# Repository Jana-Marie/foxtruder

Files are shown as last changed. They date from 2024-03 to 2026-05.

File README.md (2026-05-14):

# permanently moved to [codeberg/janam/foxtruder](https://codeberg.org/janam/foxtruder)

# foxtruder

**~~froggy~~**, **~~fog-o-nozzle~~**, **~~multimist~~**, **foxtruder [working title]** is a tiny fog machine powered by USB-PD, with Wifi and Bluetooth, based around a 3D-printer heat-cartridge and nozzle. As much as I wish to call this the worlds smallest **intentional** fog machine, sadly disposable vapes exist. Otherwise this one would be atop of the smaller fog-machines. To make it this small however, it requires an external pump, or rather a pressurized fog-fluid line, which can be connected to the 4mm pneumatic connector at the bottom. The idea here is to just have one fog-juice reservoir and pump for many fog machines. A valve on the board is used to switch the fog.

 - **Size:** 70x70x35mm
 - **Power-In:** 12-24V DC, USB-PD
 - **Communication:** RS485, DMX, WIFI, BLE, USB (Python Shell)
 - **Indication:** 4 Status LEDs, 5 Effect LEDs
 - **IO:** RS485, External IO, 2 Buttons, 4mm pneumatic push connector (fluid in), Fan Connector, I2C

Now, you might ask **why**?? To be clear, this is a stupid idea, an intrusive thought turned reality if you will, I'm not even sure if I can recommend you to replicate this. However, the tiny size combined with the low cost per machine of ~20-40€ makes this perfect for larger art-installations requiring fog. Or even better use the fog as the medium of visual art. I.e. in an array, linear arrangement, circular fashion or just many small distributed points of fog generation.

<table>
  <tbody>
    <tr>
      <td>
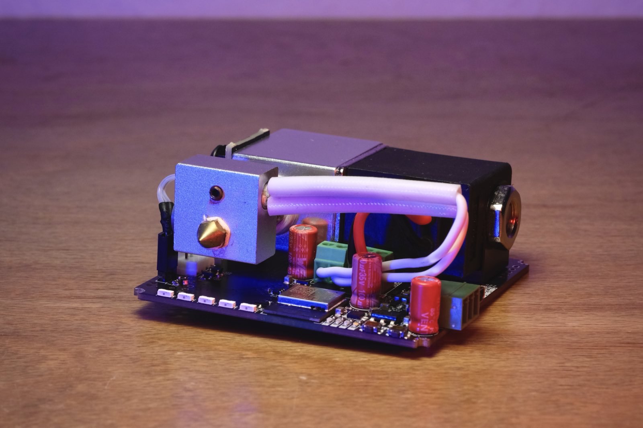
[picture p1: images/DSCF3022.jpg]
        
      </td>
      <td>
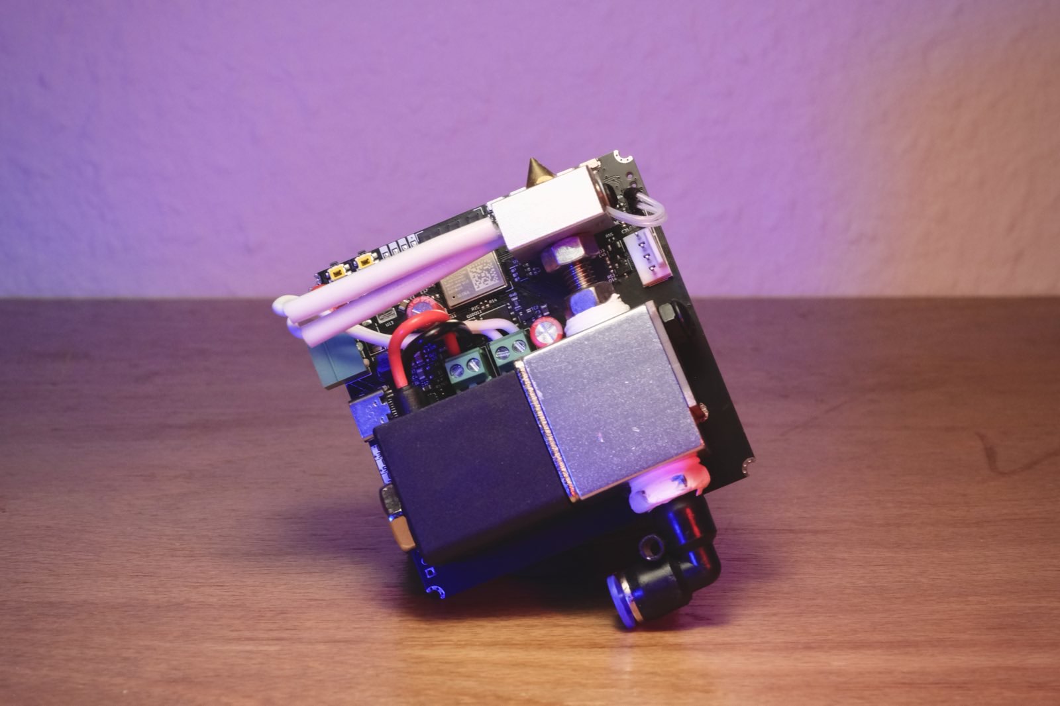
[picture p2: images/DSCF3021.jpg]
        
      </td>
    </tr>
  </tbody>
</table>

I guess this exists now, enjoy?.

<table>
  <tbody>
    <tr>
      <td width="68%">
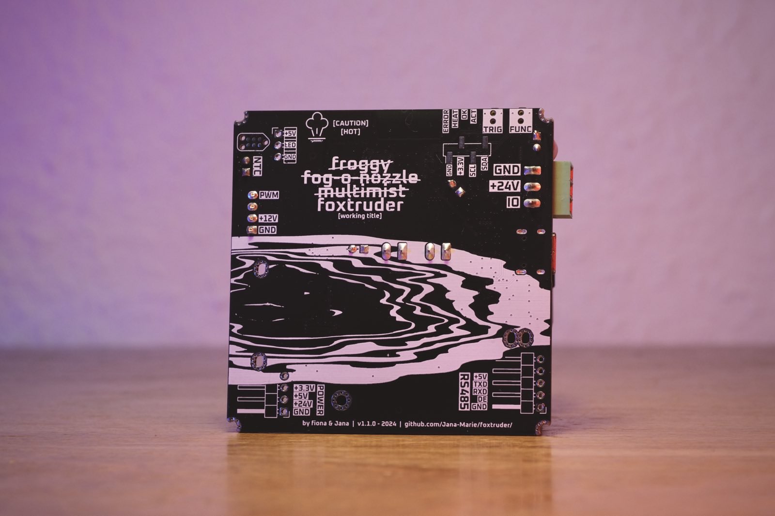
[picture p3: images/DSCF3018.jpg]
        
      </td>
      <td>
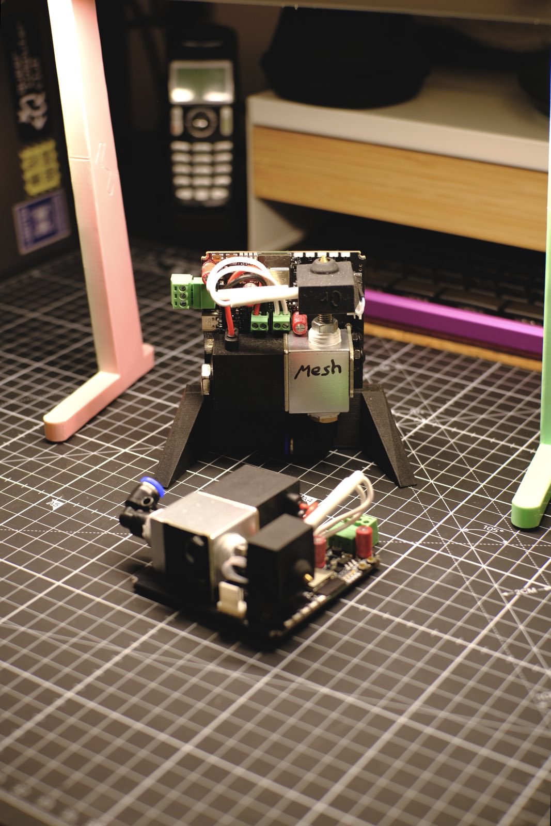
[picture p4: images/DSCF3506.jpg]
        
      </td>
    </tr>
  </tbody>
</table>

### State of this project and learnings

**It is not recommended to replicate this project in its current form, it is more of an experiment than a proper fog machine.** Issues to be solved include but are not limited to:

 - Spitting, the fog machine tends to not convert all fog-juice into fog
 - BOM cost, it should be optimized
 - Mechanical complexity, the valve-hotend interface requires some odd machining
 - Assembly complexity is too high
 - Open health questions, it seems that fog-juice may be unhealthy when heated above 190°C, however for a proper, spit-free operation temperatures well above 250-300°C might be desired (as with commercial fog machines)

### FAQ

##### Can this be run off a MacBooks USB-PD port?

Yes, that was the main mean of development.

### Initial block diagram

This needs updating, but this was the initial idea. The fog-juice tank is an external component now and the additional airflow controller to disturb the fog has not been implemented yet. Otherwise this is fairly true to foxtruder. The fog-juice tank is a real thing and has an input for pressurized air and an outlet for the liquid.

<table>
  <tbody>
    <tr>
      <td>
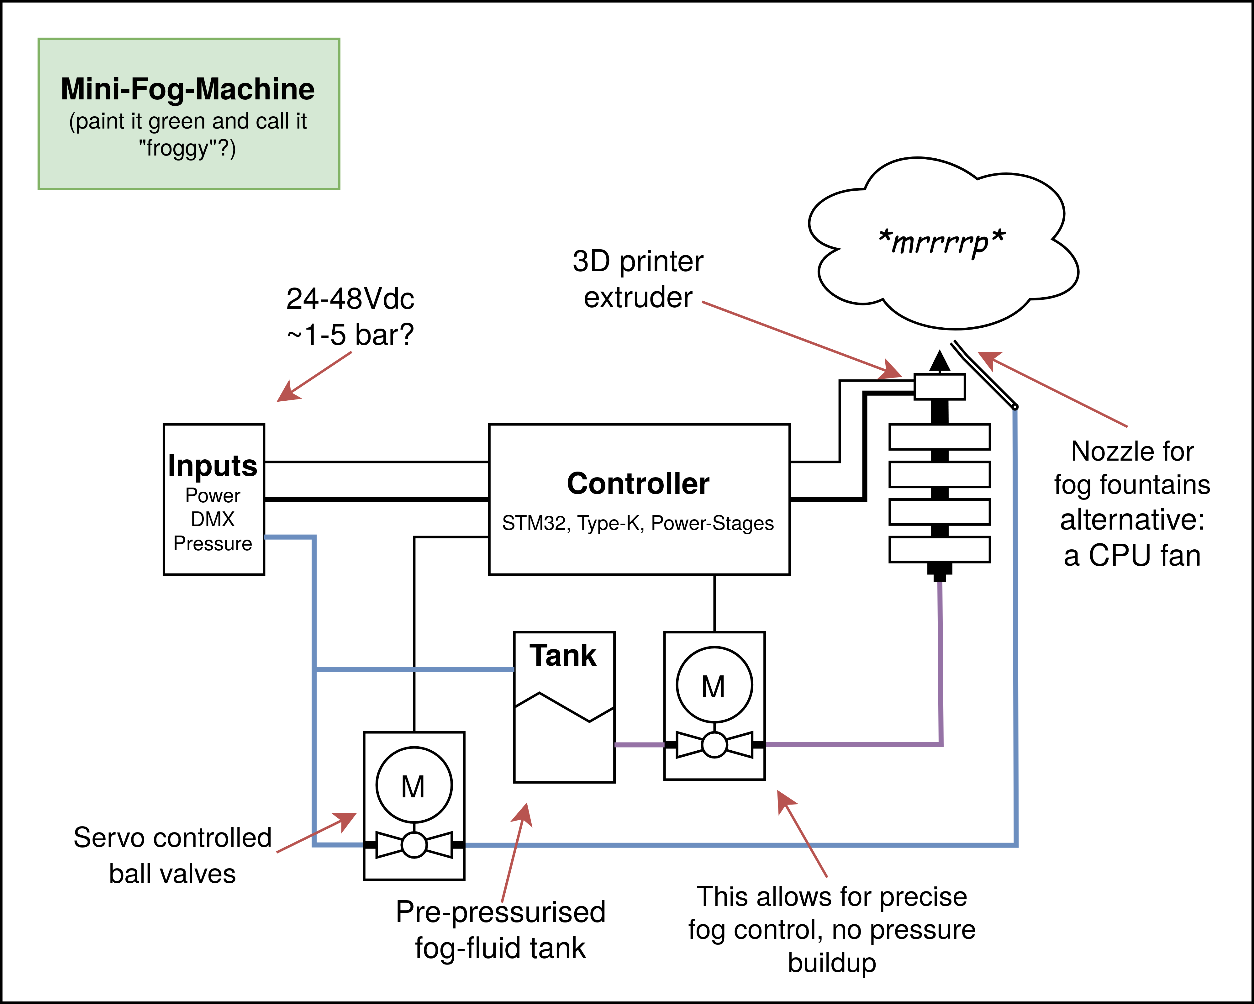
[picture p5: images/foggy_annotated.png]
        
      </td>
    </tr>
  </tbody>
</table>

### On the name

Finding a name for this project was surprisingly complicated, we just included all names we came up with. The initial idea was to "paint it green and call it froggy", like a foggy small frog sitting in the morning mist of a luscious lawn. Then we went towards focussing on the nozzle, the snoot and eventually we arrived at foxtruder, just... don't boop it, it *will* bite.

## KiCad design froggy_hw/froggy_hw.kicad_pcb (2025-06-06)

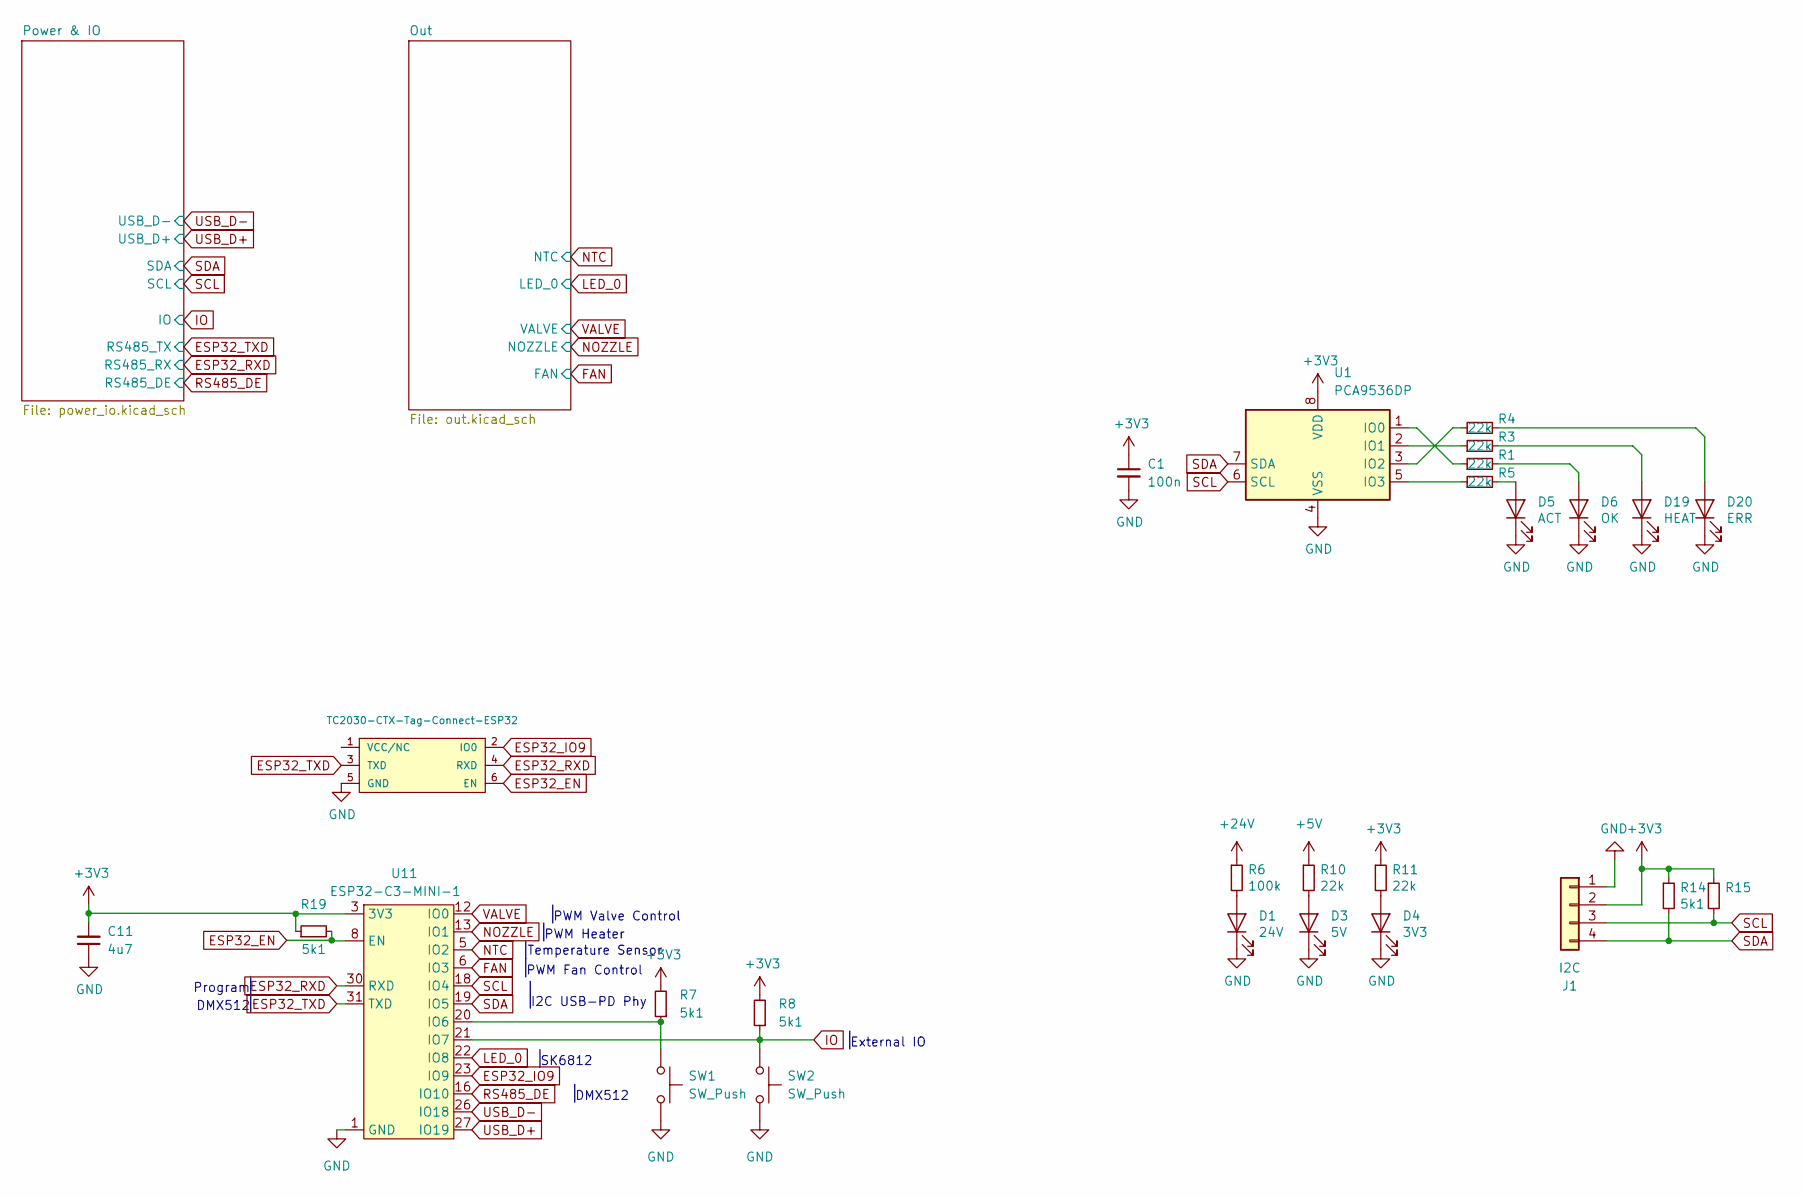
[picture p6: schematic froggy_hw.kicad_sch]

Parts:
C1: 100n; C_0402
C11: 4u7; C_0805
D1: 24V; LED_0603_1608Metric
D3: 5V; LED_0603_1608Metric
D4: 3V3; LED_0603_1608Metric
D5: ACT; LED_0603_1608Metric
D6: OK; LED_0603_1608Metric
D19: HEAT; LED_0603_1608Metric
D20: ERR; LED_0603_1608Metric
J1: I2C; PinHeader_1x04_P2.54mm_Vertical_SMD_Pin1Left
P2: TC2030-CTX-Tag-Connect-ESP32; TC2030
R1, R3, R4, R5, R10, R11: 22k; R_0402
R6: 100k; R_0402
R7, R8, R14, R15, R19: 5k1; R_0402
SW1, SW2: SW_Push; SW_SPST_EVQP7C
U1: PCA9536DP; TSSOP-8_3x3mm_P0.65mm
U11: ESP32-C3-MINI-1

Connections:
+3V3: C1.1, C11.2, J1.2, R7.2, R8.2, R11.1, R14.1, R15.1, R19.1, U1.8 (VDD), U11.3 (3V3); also elsewhere on the board
+5V: R10.1; also elsewhere on the board
+24V: R6.1; also elsewhere on the board
ESP32_EN: P2.6 (EN), R19.2, U11.8 (EN)
ESP32_IO9: P2.2 (IO0), U11.23 (IO9)
ESP32_RXD: P2.4 (RXD), U11.30 (RXD); also elsewhere on the board
ESP32_TXD: P2.3 (TXD), U11.31 (TXD); also elsewhere on the board
FAN: U11.6 (IO3)
GND: C1.2, C11.1, D1.1 (K), D3.1 (K), D4.1 (K), D5.1 (K), D6.1 (K), D19.1 (K), D20.1 (K), J1.1, P2.5 (GND), SW1.2, SW2.2, U1.4 (VSS), U11.1 (GND), U11.2 (GND), U11.11 (GND), U11.14 (GND), U11.36 (GND), U11.37 (GND), U11.38 (GND), U11.39 (GND), U11.40 (GND), U11.41 (GND), U11.42 (GND), U11.43 (GND), U11.44 (GND), U11.45 (GND), U11.46 (GND), U11.47 (GND), U11.48 (GND), U11.49 (GND), U11.50 (GND), U11.51 (GND), U11.52 (GND), U11.53 (GND); also elsewhere on the board
IO: R8.1, SW2.1, U11.21 (IO7); also elsewhere on the board
LED_0: U11.22 (IO8); also elsewhere on the board
NOZZLE: U11.13 (IO1); also elsewhere on the board
NTC: U11.5 (IO2); also elsewhere on the board
unnamed: D1.2 (A), R6.2
unnamed: D3.2 (A), R10.2
unnamed: D4.2 (A), R11.2
unnamed: D5.2 (A), R5.2
unnamed: D6.2 (A), R1.2
unnamed: D19.2 (A), R3.2
unnamed: D20.2 (A), R4.2
unnamed: R1.1, U1.1 (IO0)
unnamed: R3.1, U1.2 (IO1)
unnamed: R4.1, U1.3 (IO2)
unnamed: R5.1, U1.5 (IO3)
unnamed: R7.1, SW1.1, U11.20 (IO6)
RS485_DE: U11.16 (IO10); also elsewhere on the board
SCL: J1.3, R15.2, U1.6 (SCL), U11.18 (IO4); also elsewhere on the board
SDA: J1.4, R14.2, U1.7 (SDA), U11.19 (IO5); also elsewhere on the board
USB_D+: U11.27 (IO19); also elsewhere on the board
USB_D-: U11.26 (IO18); also elsewhere on the board
VALVE: U11.12 (IO0); also elsewhere on the board

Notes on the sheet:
External IO
SK6812
PWM Fan Control
PWM Valve Control
DMX512
PWM Heater
Temperature Sensor
Program
I2C USB-PD Phy

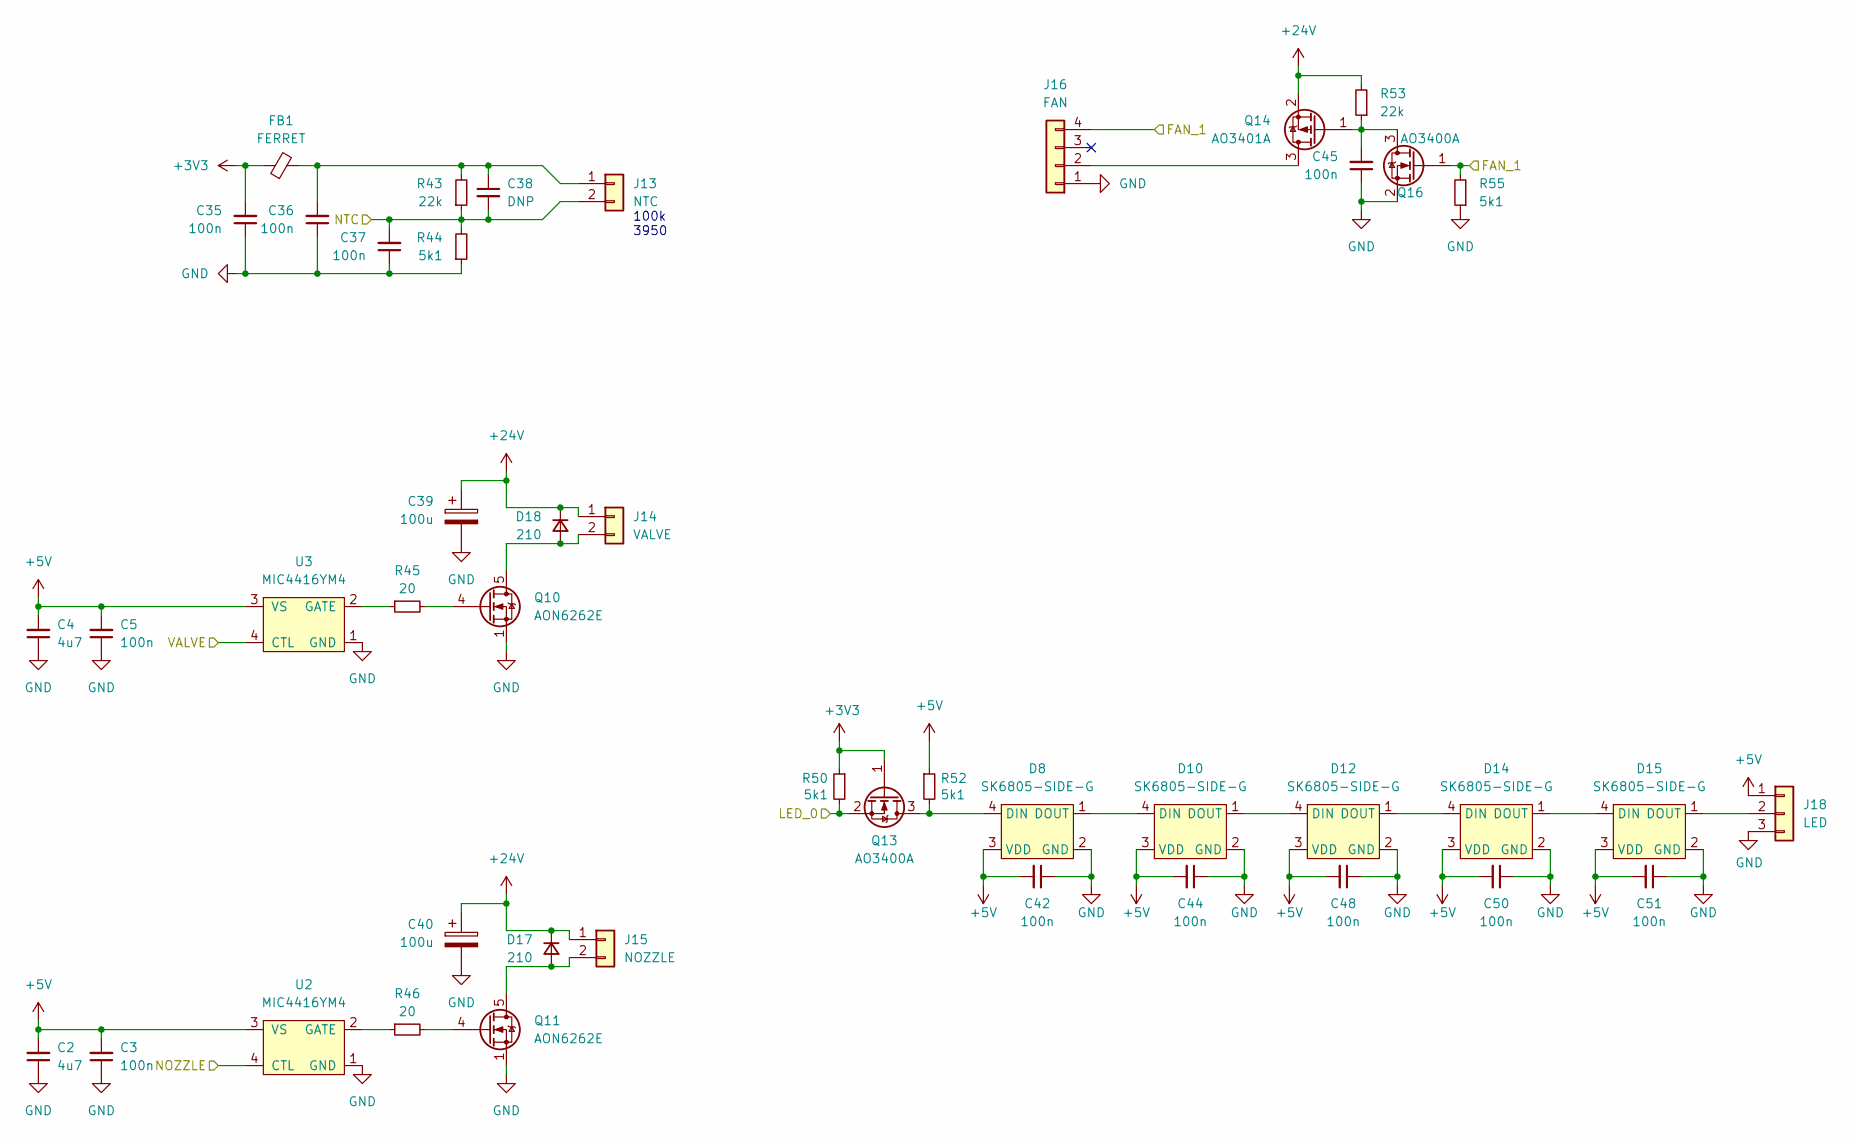
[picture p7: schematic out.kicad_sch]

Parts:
C2, C4: 4u7; C_0805
C3, C5, C35, C36, C37, C42, C44, C45, C48, C50, C51: 100n; C_0402
C38: DNP; C_0402
C39, C40: 100u; CP_Radial_D6.3mm_P2.50mm
D8, D10, D12, D14, D15: SK6805-SIDE-G
D17, D18: 210; D_SOD-123F
FB1: FERRET; R_0805
J13: NTC; PinHeader_1x02_P2.54mm_Vertical
J14: VALVE; PhoenixContact_MCV_1,5_2-G-3.5_1x02_P3.50mm_Vertical
J15: NOZZLE; PhoenixContact_MCV_1,5_2-G-3.5_1x02_P3.50mm_Vertical
J16: FAN; Molex_KK-254_AE-6410-04A_1x04_P2.54mm_Vertical
J18: LED; PinHeader_1x03_P2.54mm_Horizontal
Q10, Q11: AON6262E; TDSON-8-1
Q13, Q16: AO3400A; SOT-23
Q14: AO3401A; SOT-23
R43, R53: 22k; R_0402
R44, R50, R52, R55: 5k1; R_0402
R45, R46: 20; R_0805
U2, U3: MIC4416YM4; SOT-143

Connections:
+3V3: C35.2, FB1.1, Q13.1 (G), R50.1; also elsewhere on the board
+5V: C2.2, C3.2, C4.2, C5.2, C42.2, C44.2, C48.2, C50.2, C51.2, D8.3 (VDD), D10.3 (VDD), D12.3 (VDD), D14.3 (VDD), D15.3 (VDD), J18.1, R52.1, U2.3 (VS), U3.3 (VS); also elsewhere on the board
+24V: C39.1, C40.1, D17.1 (K), D18.1 (K), J14.1, J15.1, Q14.2 (S), R53.2; also elsewhere on the board
/Out/FAN_1: J16.4, Q16.1 (G), R55.2
GND: C2.1, C3.1, C4.1, C5.1, C35.1, C36.1, C37.1, C39.2, C40.2, C42.1, C44.1, C45.1, C48.1, C50.1, C51.1, D8.2 (GND), D10.2 (GND), D12.2 (GND), D14.2 (GND), D15.2 (GND), J16.1, J18.3, Q10.1 (S), Q10.2 (S), Q10.3 (S), Q11.1 (S), Q11.2 (S), Q11.3 (S), Q16.2 (S), R44.1, R55.1, U2.1 (GND), U3.1 (GND); also elsewhere on the board
LED_0: Q13.2 (S), R50.2; also elsewhere on the board
NOZZLE: U2.4 (CTL); also elsewhere on the board
NTC: C37.2, C38.2, J13.2, R43.1, R44.2; also elsewhere on the board
unnamed: D8.4 (DIN), Q13.3 (D), R52.2
unnamed: D8.1 (DOUT), D10.4 (DIN)
unnamed: D10.1 (DOUT), D12.4 (DIN)
unnamed: D12.1 (DOUT), D14.4 (DIN)
unnamed: D14.1 (DOUT), D15.4 (DIN)
unnamed: D15.1 (DOUT), J18.2
unnamed: D17.2 (A), J15.2, Q11.5 (D)
unnamed: D18.2 (A), J14.2, Q10.5 (D)
unnamed: C36.2, C38.1, FB1.2, J13.1, R43.2
unnamed: J16.2, Q14.3 (D)
unnamed: Q10.4 (G), R45.2
unnamed: Q11.4 (G), R46.2
unnamed: C45.2, Q14.1 (G), Q16.3 (D), R53.1
unnamed: R46.1, U2.2 (GATE)
unnamed: R45.1, U3.2 (GATE)
VALVE: U3.4 (CTL); also elsewhere on the board

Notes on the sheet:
100k 3950

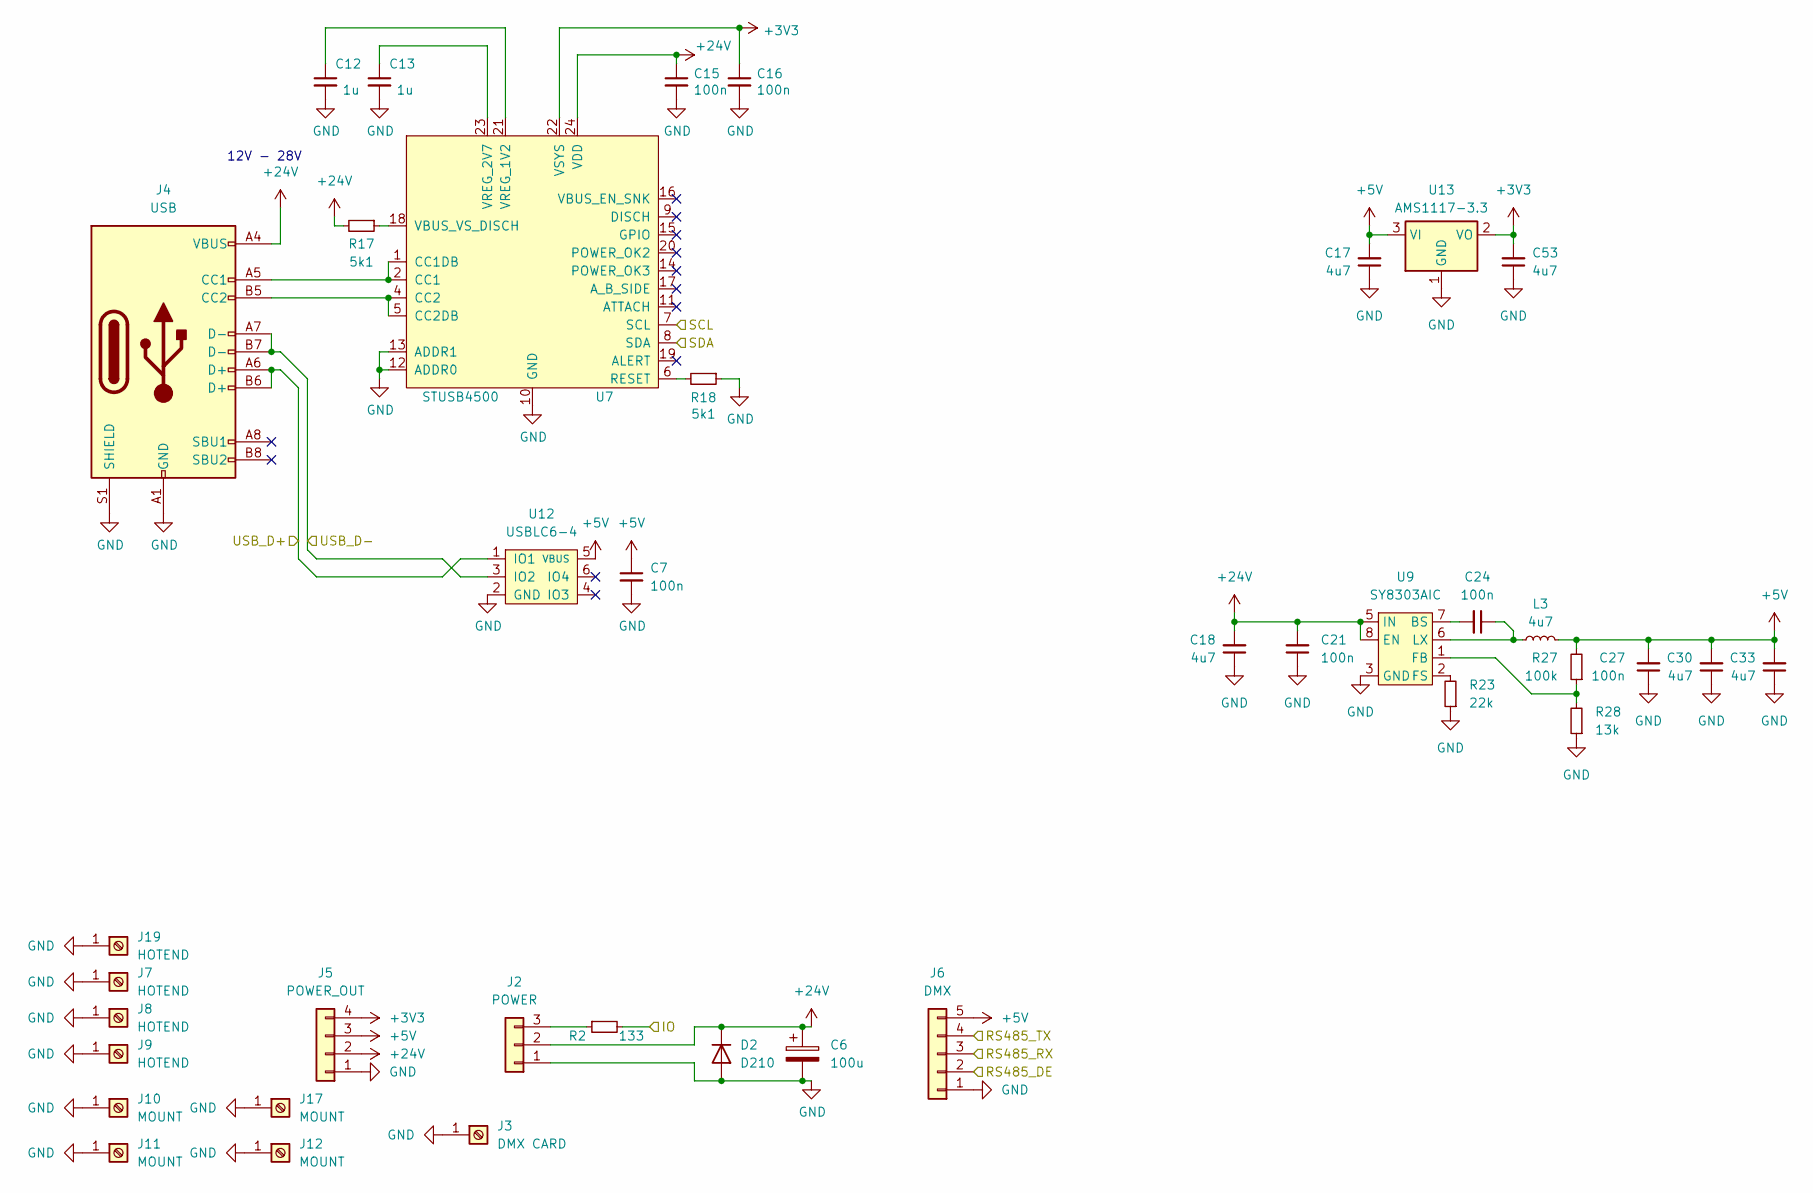
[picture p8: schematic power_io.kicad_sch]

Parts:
C6: 100u; CP_Radial_D6.3mm_P2.50mm
C7, C15, C16, C21, C27: 100n; C_0402
C12, C13: 1u; C_0603
C17, C18, C30, C33, C53: 4u7; C_0805
C24: 100n; C_0603
D2: D210; D_SMA
J2: POWER; PhoenixContact_MC_1,5_3-G-3.5_1x03_P3.50mm_Horizontal
J3: DMX CARD; MountingHole_2.2mm_M2_Pad_Via
J4: USB; USB-C 16Pin
J5: POWER_OUT; PinHeader_1x04_P2.54mm_Horizontal
J6: DMX; PinHeader_1x05_P2.54mm_Horizontal
J7, J8, J9, J19: HOTEND; froggy_PAD
J10, J11, J12, J17: MOUNT; MountingHole_2.2mm_M2_Pad_Via
L3: 4u7; L_Taiyo-Yuden_MD-4040
R2: 133; R_0805
R17, R18: 5k1; R_0402
R23: 22k; R_0402
R27: 100k; R_0402
R28: 13k; R_0402
U7: STUSB4500; QFN-24-1EP_4x4mm_P0.5mm_EP2.7x2.7mm
U9: SY8303AIC; TSOT-23-8
U12: USBLC6-4; SOT-23-6
U13: AMS1117-3.3; SOT-223-3_TabPin2

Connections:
+3V3: C16.1, C53.2, J5.4, U7.22 (VSYS), U13.2 (VO); also elsewhere on the board
+5V: C7.1, C17.2, C27.2, C30.2, C33.2, J5.3, J6.5, L3.2, R27.2, U12.5 (VBUS), U13.3 (VI); also elsewhere on the board
+24V: C6.1, C15.1, C18.2, C21.2, D2.1 (K), J2.2, J4.A4 (VBUS), J4.A9 (VBUS), J4.B4 (VBUS), J4.B9 (VBUS), J5.2, R17.2, U7.24 (VDD), U9.5 (IN), U9.8 (EN); also elsewhere on the board
ESP32_RXD: J6.3; also elsewhere on the board
ESP32_TXD: J6.4; also elsewhere on the board
GND: C6.2, C7.2, C12.2, C13.2, C15.2, C16.2, C17.1, C18.1, C21.1, C27.1, C30.1, C33.1, C53.1, D2.2 (A), J2.1, J3.1, J4.A1 (GND), J4.A12 (GND), J4.B1 (GND), J4.B12 (GND), J4.S1 (SHIELD), J5.1, J6.1, J7.1, J8.1, J9.1, J10.1, J11.1, J12.1, J17.1, J19.1, R18.1, R23.1, R28.1, U7.10 (GND), U7.12 (ADDR0), U7.13 (ADDR1), U7.25 (GND), U9.3 (GND), U9.4 (GND), U12.2 (GND), U13.1 (GND); also elsewhere on the board
IO: R2.2; also elsewhere on the board
unnamed: J2.3, R2.1
unnamed: J4.A5 (CC1), U7.1 (CC1DB), U7.2 (CC1)
unnamed: J4.B5 (CC2), U7.4 (CC2), U7.5 (CC2DB)
unnamed: R18.2, U7.6 (RESET)
unnamed: R17.1, U7.18 (VBUS_VS_DISCH)
unnamed: C12.1, U7.21 (VREG_1V2)
unnamed: C13.1, U7.23 (VREG_2V7)
unnamed: C24.2, U9.7 (BS)
unnamed: R27.1, R28.2, U9.1 (FB)
unnamed: R23.2, U9.2 (FS)
unnamed: C24.1, L3.1, U9.6 (LX)
RS485_DE: J6.2; also elsewhere on the board
SCL: U7.7 (SCL); also elsewhere on the board
SDA: U7.8 (SDA); also elsewhere on the board
USB_D+: J4.A6 (D+), J4.B6 (D+), U12.1 (IO1); also elsewhere on the board
USB_D-: J4.A7 (D-), J4.B7 (D-), U12.3 (IO2); also elsewhere on the board

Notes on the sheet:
12V - 28V

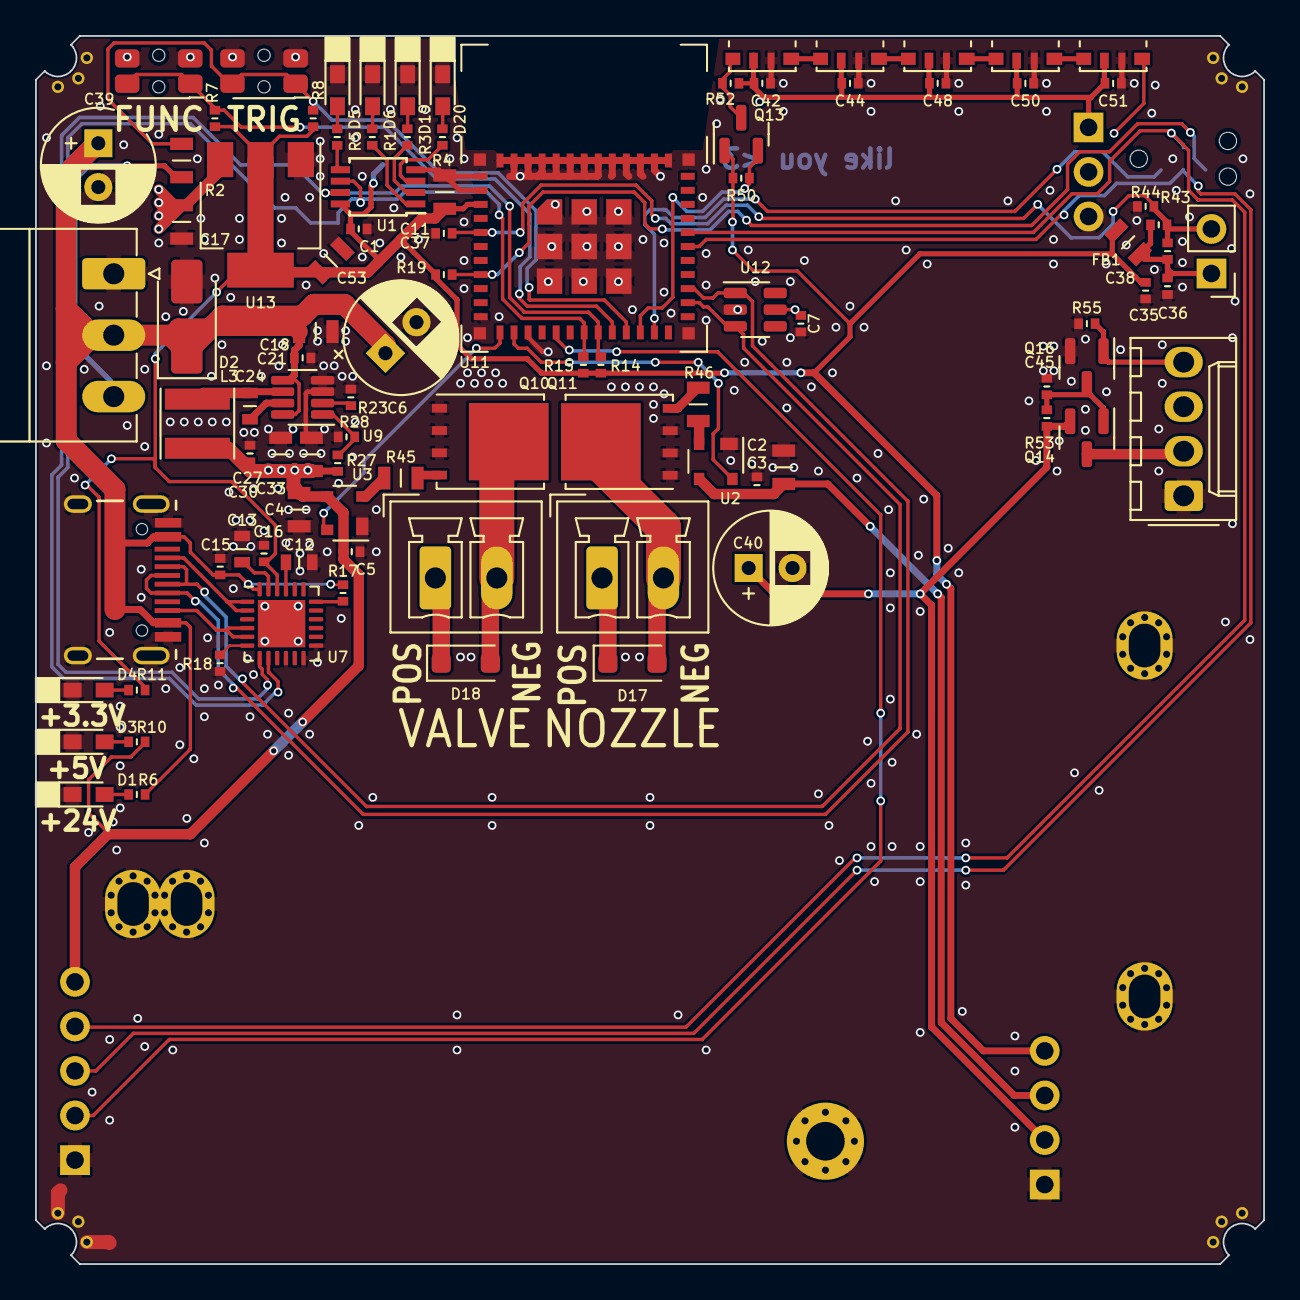
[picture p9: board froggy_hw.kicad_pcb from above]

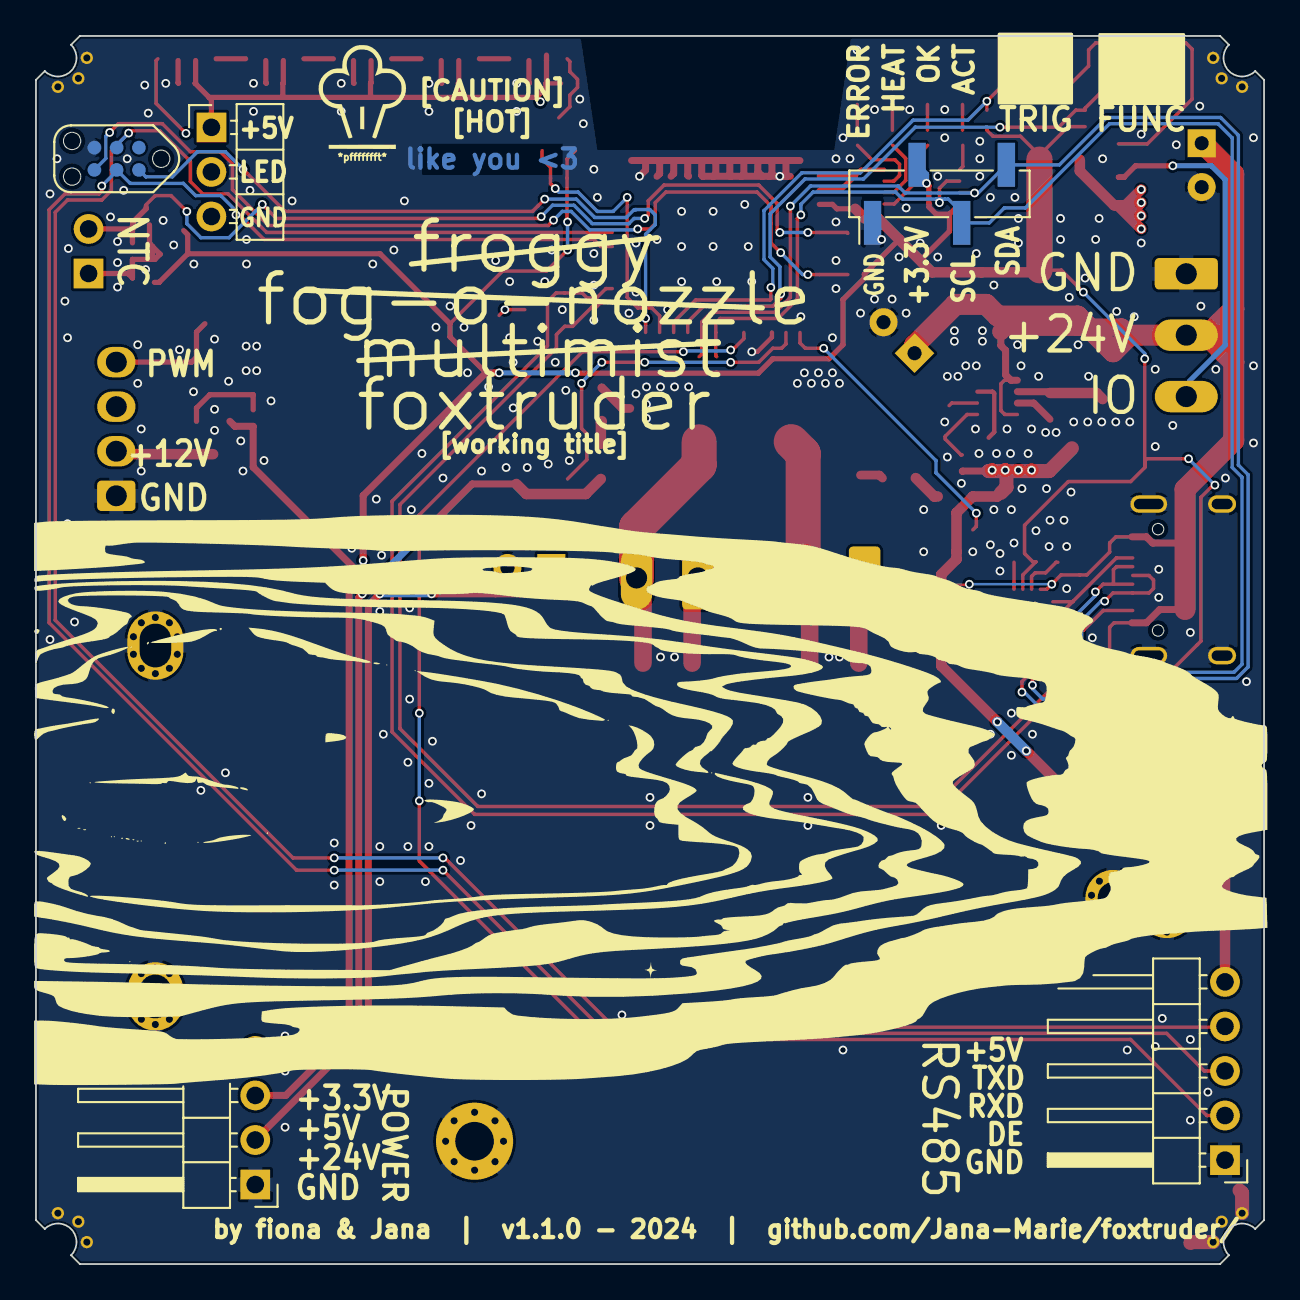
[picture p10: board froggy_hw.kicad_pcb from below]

Board: 4 copper layers, 70.0 x 70.0 mm, 110 parts (5 on the bottom side), 57 nets.

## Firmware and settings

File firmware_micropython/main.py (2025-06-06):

from machine import Pin, I2C, PWM, ADC
import time
import neopixel

# Board Constants
LED_READY = 0
LED_VALVE = 3
LED_HOTEND = 1
LED_ERROR = 2

LED_SK6812 = Pin(8)

ADC_TEMP = Pin(2)

PWM_PIN_VALVE = Pin(0)
PWM_PIN_HOTEND = Pin(1)

I2C0_SCL = Pin(4)
I2C0_SDA = Pin(5)
I2C0_PCA9536_ADDR = 65

BUTTON_FUNC = Pin(6, Pin.IN, Pin.PULL_UP)
BUTTON_TRIG = Pin(7, Pin.IN, Pin.PULL_UP)

# State
ledState = 0
error = False
active = False
i2c = None
hotend = None
valve = None
tempsens = None
rgbLeds = None

def setBit(v, index, x):
    mask = 1 << index
    v &= ~mask
    v |= x << index
    return v

def initHardware():
    global i2c, hotend, valve, tempsens, rgbLeds

    # LEDs on PCA9536 IO Expander
    #i2c = I2C(0, scl=I2C0_SCL, sda=I2C0_SDA)
    # intialize pins as outputs
    #i2c.writeto(I2C0_PCA9536_ADDR, bytes([0x03, 0x00]))
    # disable all LEDs
    #i2c.writeto(I2C0_PCA9536_ADDR, bytes([0x01, ledState]))

    # SK6812 LEDs
    rgbLeds = neopixel.NeoPixel(LED_SK6812, 5, 3)

    # PWM
    # Hotend
    hotend = PWM(PWM_PIN_HOTEND, freq=20000, duty_u16=512)
    hotend.duty(0)
    # Valve
    valve = PWM(PWM_PIN_VALVE, freq=20000, duty_u16=512) 
    valve.duty(0)

    # Temperature Sensor
    tempsens = ADC(ADC_TEMP, atten=ADC.ATTN_11DB)

    # Set button interrupt handler
    BUTTON_TRIG.irq(trigger=Pin.IRQ_RISING|Pin.IRQ_FALLING, handler=handleTrigPress)
    BUTTON_FUNC.irq(trigger=Pin.IRQ_RISING, handler=handleFuncPress)

def handleFuncPress(pin):
    global active, error
    if not active or error:
        print("Function button pressed, activating..")
        active = True
        error = False
        setLED(LED_READY, 1)

def handleTrigPress(pin):
    time.sleep(0.01)
    if pin.value():
        setValve(False)
    else:
        setValve(True)

def setLED(ledIndex, val):
    global ledState

    ledState = setBit(ledState, ledIndex, val)
    #i2c.writeto(I2C0_PCA9536_ADDR, bytes([0x01, ledState]))

def setHotend(value):
    global hotend

    print(f"Setting hot end to {value}")
    if value == 0:
        setLED(LED_HOTEND, 0)
    else:
        setLED(LED_HOTEND, 1)
    hotend.duty(value)

def setValve(value):
    global valve

    print(f"Setting valve to {value}")
    if value:
        setLED(LED_VALVE, 1)
        valve.duty(250)
    else:
        setLED(LED_VALVE, 0)
        valve.duty(0)

def readTemp():
    global tempsens
    return tempsens.read_uv()

def convertTemp(rawTemp):
    poly1 = 1.79E-04 * rawTemp
    poly2 = -8.8E-11 * rawTemp ** 2
    poly3 = 2.04E-17 * rawTemp ** 3
    return 23 + poly1 + poly2 + poly3

initHardware()

rgbLeds.fill(bytes([30, 6, 0]))
rgbLeds.write()
 
setHotend(0)

while True:
    temp = convertTemp(readTemp())
    print(f"Raw Temperature: {readTemp()}")
    print(f"Temperature: {temp}")

    if temp > 230:
        setHotend(0)
        setValve(False)
        setLED(LED_READY, 0)
        setLED(LED_ERROR, 1)
        print("Error, stopping operation")
        break

    tTarget = 220
    tReal = temp
    tDelta = tTarget - tReal

    if active and not error:
        if tDelta > 30:
            setHotend(1023)
        elif tDelta > 5:
            if BUTTON_TRIG.value():
                setHotend(800)
            else:
                setHotend(1000)
        elif tReal < tTarget and tDelta > -5:
            if BUTTON_TRIG.value():
                setHotend(160)
            else:
                setHotend(254)
        else:
            setHotend(0)

    time.sleep(0.5)

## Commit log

2024-03-10 added hw
    [froggy_bridge.kicad_pcb, froggy_bridge.kicad_sch, froggy_hw.kicad_pcb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]
2024-05-29 moved to esp32
    [froggy_hw.kicad_pcb, froggy_hw.kicad_sch, out.kicad_sch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]
2024-05-29 added supplementaaary file
    [froggy_bridge.kicad_pcb, froggy_bridge.kicad_sch]
2025-06-06 updated to new kicad version
    [froggy_hw.kicad_pcb, froggy_hw.kicad_sch, out.kicad_sch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]
